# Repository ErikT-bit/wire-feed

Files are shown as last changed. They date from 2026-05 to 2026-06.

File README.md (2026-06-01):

# Wire EDM Wire-Feed System

This repository contains the software, supporting libraries, and mechanical CAD files for a Wire EDM wire-feed and wire-tension system.

The system uses a motor-driven wire-pull mechanism and an electronically controlled wire brake. The brake is implemented with a moteus motor controller and is intended to maintain controlled resistance on the wire spool while the wire is pulled through the machine.

## Repository Layout

```text
wire-feed/
|-- code/
|   |-- pi_brake_controller/
|   `-- WireTension code V1/
|-- libraries/
`-- mechanical/
```

## `code/`

This directory contains the project-specific control software.

### `code/pi_brake_controller/`

This is the current Raspberry Pi brake-controller implementation.

The software supports communication between the machine controller and the moteus-based wire brake. The folder includes the Raspberry Pi brake daemon, operator-facing console, service configuration, autostart configuration, hardware-detection utility, and a fake brake server for testing without hardware.

The Raspberry Pi brake-controller code in this folder was written by Nathan Taylor with development assistance from Claude Code.

See [`code/pi_brake_controller/README.md`](code/pi_brake_controller/README.md) for the system architecture, setup instructions, operator workflow, troubleshooting notes, and file-by-file authorship credit.

### `code/WireTension code V1/`

This folder contains an earlier version of the wire-tension control software. It is retained as a reference for the development history of the project.

## `libraries/`

This directory contains supporting libraries retained with the project for development and reference.

Included libraries:

- `ACAN2517`
- `ACAN2517FD`
- `AccelStepper`
- `HX711_Arduino_Library`
- `Moteus`

These libraries are third-party dependencies or reference libraries. Their original licenses, README files, and attribution information are preserved inside their respective folders.

## `mechanical/`

This directory contains the mechanical CAD files for the Wire EDM wire-feed and wire-tension hardware.

The folder includes:

- Native SolidWorks assembly files
- Native SolidWorks part files
- Exported `.STEP`, `.STL`, and `.3mf` files
- Files organized by subsystem, including pulleys, nozzles, custom tools, the wire-collection system, the wire-pull axle assembly, and the wire-tension housing

See [`mechanical/README.md`](mechanical/README.md) for the detailed CAD-file inventory and mechanical-design credit.

## Calibration And Tuning Data

Calibration data and the tuning workflow used during development are kept in a separate repository:

[Wire-EDM-Tension-Calibration](https://github.com/ErikT-bit/Wire-EDM-Tension-Calibration)

The `data/` folder is not part of this repository layout for the GitHub push.

## Important Note About Moteus Brake Tuning

The moteus controller must be tuned for the specific motor and mechanical setup being used.

The `Kd` values used in this project were developed for this particular wire-brake assembly, motor, spool geometry, pulley arrangement, and operating range. Those values should **not** be assumed to work correctly or safely in another system.

Anyone adapting this project should calibrate and test their own wire brake before operating the machine. A different motor, spool diameter, gear ratio, pulley layout, wire path, or target tension range may require different moteus settings and different `Kd` values.

## Project Documentation

Additional documentation is available inside the relevant folders:

- [`code/pi_brake_controller/README.md`](code/pi_brake_controller/README.md) - brake-controller architecture, setup, operation, troubleshooting, and software credit
- [`mechanical/README.md`](mechanical/README.md) - CAD-file inventory and mechanical-design credit

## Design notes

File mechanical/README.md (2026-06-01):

# Mechanical CAD Files

This directory contains the mechanical CAD models, assemblies, and exported manufacturing files for the Wire EDM wire-feed and wire-tension system.

Some designs appear in more than one file format or in more than one subsystem folder. Native SolidWorks files are included where available, while `.STEP`, `.STL`, and `.3mf` files are included for manufacturing, sharing, or 3D printing.

## Folder Layout

- `CAD Assembly Files/` - native SolidWorks assemblies
- `CAD PART Files/` - native SolidWorks parts and some assembly files stored with their related parts
- `CAD STEP Files/` - exported manufacturing and sharing files, organized by subsystem
- `CAD STEP Files/Custom Tools/` - tool and calibration exports
- `CAD STEP Files/Nozzles/` - nozzle exports
- `CAD STEP Files/Pulleys/` - pulley exports
- `CAD STEP Files/Wire Collection System/` - wire collection subsystem exports
- `CAD STEP Files/Wire Pull Axle Assembly/` - wire-pull axle subsystem exports
- `CAD STEP Files/Wire Tension Housing/` - wire-tension housing subsystem exports

SolidWorks lock or owner files beginning with `~$` are not design-credit entries.

## Contributors

### Nathan Erik Taylor

The following specific CAD designs and exported files were created by **Nathan Erik Taylor**.

#### SolidWorks Assembly Files

Located in `CAD Assembly Files/`.

- `EDM Spool Small.SLDASM`
- `EDM Wire Tension Housing Assembly V6.SLDASM`

#### SolidWorks Part And Assembly Files

Located in `CAD PART Files/`.

- `Captured Pulley V5.SLDPRT`
- `EDM Axle Support.SLDPRT`
- `EDM Bambu Inner Spool With Bearings.SLDPRT`
- `EDM Brake_Motor_Mount_Plate.SLDPRT`
- `EDM Custom Spool 1 of 2.SLDPRT`
- `EDM Custom Spool 2 of 2.SLDPRT`
- `EDM Custom Spool Small.SLDASM`
- `EDM Driver Pulley V4.SLDPRT`
- `EDM Power Cover.SLDPRT`
- `EDM Pulley-Spacer.SLDPRT`
- `EDM Receiver Nozzle.SLDPRT`
- `EDM Receiver Pulley.SLDPRT`
- `EDM Shrinkage Gauge.SLDPRT`
- `EDM Sled Spacer V2.SLDPRT`
- `EDM Slip Spool (split for assembly).SLDPRT`
- `EDM Spool Ends.SLDPRT`
- `EDM Threading Tool.SLDPRT`
- `EDM V2-Spool Mount (LEFT and RIGHT).SLDPRT`
- `EDM Water nozzel V8 (with 10mm hole).SLDPRT`
- `EDM Wire Bumper.SLDPRT`
- `EDM Wire Home Calibration Part 1 of 2.SLDPRT`
- `EDM Wire Home Calibration Part 2 of 2.SLDPRT`
- `EDM Wire Tension Housing Assembly V6.SLDASM`
- `Threaded pulley reverse thread V5.SLDPRT`

#### Exported CAD Files

##### Custom Tools

Located in `CAD STEP Files/Custom Tools/`.

- `EDM Shrinkage Gauge.STEP`
- `EDM Threading Tool.STEP`
- `EDM Wire Home Calibration Part 1 of 2.STEP`
- `EDM Wire Home Calibration Part 2 of 2.STEP`

##### Nozzles

Located in `CAD STEP Files/Nozzles/`.

- `EDM Receiver Nozzle.STEP`
- `EDM Water nozzel V8 (with 10mm hole).STEP`

##### Pulleys

Located in `CAD STEP Files/Pulleys/`.

- `Captured Pulley V5.STEP`
- `EDM Driver Pulley V4.STEP`
- `EDM Pulley-Spacer.3mf`
- `EDM Receiver Pulley.STEP`
- `Threaded pulley reverse thread V5.STEP`

##### Wire Collection System

Located in `CAD STEP Files/Wire Collection System/`.

- `EDM Bambu Inner Spool With Bearings.STEP`
- `EDM Custom Spool 1 of 2.STEP`
- `EDM Custom Spool 2 of 2.STEP`
- `EDM Slip Spool (split for assembly).STEP`
- `EDM Spool Ends.STEP`
- `EDM V2-Spool Mount (LEFT and RIGHT).STEP`

##### Wire Pull Axle Assembly

Located in `CAD STEP Files/Wire Pull Axle Assembly/`.

- `EDM Axle Support.STEP`
- `EDM Driver Pulley V4.STEP`
- `EDM Pulley-Spacer.STEP`
- `EDM Sled Spacer V2.STEP`

##### Wire Tension Housing

Located in `CAD STEP Files/Wire Tension Housing/`.

- `Captured Pulley V5.STEP`
- `EDM Brake_Motor_Mount_Plate.STEP`
- `EDM FACEPLATE.3mf`
- `EDM FACEPLATE.STEP`
- `EDM Power Cover.STEP`
- `EDM Wire Bumper.STEP`
- `EDM Wire Tension Housing Assembly V6.STEP`
- `Threaded pulley reverse thread V5.STEP`

### @koolm

The following pulley files were generated using a MakerWorld generative design tool created by **@koolm**.

#### Pulleys

Located in `CAD STEP Files/Pulleys/`.

- `18 Tooth T5 Pulley 8mm bore.3mf`
- `EDM 59 Tooth 8mm bore.stl`

#### Copies Used In Subsystem Folders

- `CAD STEP Files/Wire Collection System/18 Tooth T5 Pulley 8mm bore.3mf`
- `CAD STEP Files/Wire Pull Axle Assembly/EDM 59 Tooth 8mm bore.stl`

### Jacob Kasch

Files contributed by **Jacob Kasch** can be listed here as they are added.

### Kieran Dolan

Files contributed by **Kieran Dolan** can be listed here as they are added.

### Jorge Sandoval

Files contributed by **Jorge Sandoval** can be listed here as they are added.

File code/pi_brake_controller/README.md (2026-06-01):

# Wire EDM Brake Controller

Electronic braking system for a Wire EDM machine. The brake torque is
delivered by a moteus r4.11 motor controller acting as a velocity-zero
damper on the wire spool. A Raspberry Pi 3B+ commands the moteus over
CAN-FD via a pi3hat r4.5; a Raspberry Pi 5 (LinuxCNC main controller)
provides the operator interface over an ethernet TCP link.

The operator never has to log into the Pi 3 or know any "machine codes" —
they sit in front of the Pi 5, see plain-English prompts on screen, and
type a velocity and tension. The Pi 3 computes the moteus damping value
and engages the brake.

## System architecture

```
                +-----------------------------+
                |  Raspberry Pi 5 (LinuxCNC)  |
                |  10.10.10.1                 |
                |  - Mesa motion via hm2_eth  |
                |  - brake_console.py (xterm) |
                +--------------+--------------+
                               |
                               | ethernet
                               v
                +--------------+--------------+
                |    Unmanaged ethernet switch    |
                +--+-------------+-------------+--+
                   |             |             |
                   |             |             |
        +----------+--+   +------+------+   +--+----------+
        | Mesa 7i76EU |   | Raspberry  |   |             |
        | 10.10.10.10 |   | Pi 3B+     |   | (laptop, when
        | (motion)    |   | 10.10.10.20|   |  pushing code)
        +-------------+   +-----+------+   +-------------+
                                |
                                | pi3hat r4.5 -> CAN bus 1 (JC1)
                                v
                        +-------+-------+
                        | moteus r4.11  |
                        | (electric     |
                        |  brake)       |
                        +---------------+
                                |
                                | 3-phase
                                v
                        +-------+-------+
                        | BLDC on wire  |
                        | spool         |
                        +---------------+
```

## Hardware

| Item | Role | Notes |
|---|---|---|
| Raspberry Pi 5 | Machine main / operator UI | Runs LinuxCNC + Mesa driver + brake console |
| Raspberry Pi 3B+ | Brake controller | Headless, runs `wire_brake.py` as a systemd service |
| pi3hat r4.5 | CAN-FD interface | Sits on the Pi 3B+'s 40-pin GPIO header |
| moteus r4.11 | Motor controller / brake | Connected to pi3hat JC1 (CAN bus 1), CAN ID 1 |
| 24 V bench supply | moteus high-voltage power | ~12–44 V is acceptable |
| Mesa 7i76EU | Motion controller for the wire-puller | Static IP 10.10.10.10 (factory default) |
| Unmanaged ethernet switch | Connects Pi 5, Pi 3B+, Mesa | No DHCP, all devices use static IPs |

## Network configuration

| Device | IP / subnet | Notes |
|---|---|---|
| Pi 5 (`eth0`) | `10.10.10.1/24`  | NetworkManager static profile |
| Mesa 7i76EU | `10.10.10.10/24` | Factory default, do not change |
| Pi 3B+ (`eth0`) | `10.10.10.20/24` | NetworkManager static profile |

The Pi 5 also has WiFi (`wlan0`) for development/file-transfer; it is not
used by the brake system. The Pi 3B+ is intended to be wired-only at the
machine.

## Files

| File | Where it runs | Purpose |
|---|---|---|
| `wire_brake.py` | Pi 3B+ | TCP server daemon; talks to moteus, runs the brake state machine |
| `brake_console.py` | Pi 5 | Operator-facing TCP client; relays text to/from `wire_brake.py` |
| `detect_moteus.py` | Pi 3B+ | One-shot moteus communication test, no motion |
| `fake_brake_server.py` | Anywhere | Stand-in for `wire_brake.py` for testing without hardware |
| `wire-brake.service` | Pi 3B+ (`/etc/systemd/system/`) | systemd unit for auto-start at boot |
| `brake-console.desktop` | Pi 5 (`~/.config/autostart/`) | XFCE autostart entry for the operator console |

## The brake control law

The moteus runs in `position` mode with `position = NaN`, `velocity = 0`,
`kp_scale = 0`, and `kd_scale = Kd`. With `kp_scale = 0` the position term
is disabled, so the controller only resists *motion* — exactly what a
brake should do. The braking torque is proportional to the velocity the
puller forces on the spool.

The damping coefficient `Kd` is computed from the operator's requested
wire speed and tension using a fitted equation:

```
Kd = 0.560 - 0.218 v + 2.246 T - 0.107 v T + 0.0126 v^2 - 0.122 T^2
```

where `v` is wire velocity in m/min and `T` is wire tension in kgf.

The equation is calibrated for the envelope `v ∈ [5, 15] m/min`,
`T ∈ [0.2, 3] kgf`. Inputs outside that envelope are rejected before any
moteus command is issued.

## Pi 3B+ setup

One-time install steps. Assumes Raspberry Pi OS 64-bit (Lite or Desktop)
and a user named `admin` with a home directory at `/home/admin`.

### 1. System packages

```bash
sudo apt update
sudo apt install -y tmux python3-pip python3-venv python3-dev build-essential git
```

### 2. Enable SPI (required by pi3hat)

```bash
sudo raspi-config nonint do_spi 0
```

### 3. Bump swap to 2 GB (recommended on the 1 GB Pi 3B+ for the moteus install)

```bash
sudo dphys-swapfile swapoff
sudo sed -i 's/^CONF_SWAPSIZE=.*/CONF_SWAPSIZE=2048/' /etc/dphys-swapfile
sudo dphys-swapfile setup
sudo dphys-swapfile swapon
```

### 4. Install moteus + moteus-pi3hat in a venv

```bash
mkdir -p ~/moteus && cd ~/moteus
python3 -m venv venv
source venv/bin/activate
pip install --upgrade pip wheel setuptools
pip install moteus moteus-pi3hat
```

### 5. Drop the brake controller files into `~/wirebrake/`

Copy `wire_brake.py`, `detect_moteus.py`, and `wire-brake.service` to
`/home/admin/wirebrake/`. Either via scp from a laptop or by cloning this
repo and copying out of `WireTension/`.

### 6. Install the systemd service

```bash
sudo cp ~/wirebrake/wire-brake.service /etc/systemd/system/wire-brake.service
sudo systemctl daemon-reload
sudo systemctl enable --now wire-brake.service
sudo systemctl status wire-brake
```

You should see `active (running)` and `[boot] listening on ('0.0.0.0', 5005)`
in the journal output.

### 7. Static ethernet IP (run at the Pi 3B+ console)

```bash
sudo nmcli con mod "Wired connection 1" ipv4.method manual ipv4.addresses 10.10.10.20/24 ipv6.method disabled
sudo nmcli con down "Wired connection 1"; sudo nmcli con up "Wired connection 1"
ip a show eth0
```

Confirm `inet 10.10.10.20/24` is shown on `eth0`.

## Pi 5 setup

Assumes the LinuxCNC bundled Debian image with NetworkManager and XFCE
desktop, user `admin`.

### 1. Static ethernet IP

```bash
sudo nmcli con mod "Wired connection 1" ipv4.method manual ipv4.addresses 10.10.10.1/24 ipv6.method disabled
sudo nmcli con down "Wired connection 1"; sudo nmcli con up "Wired connection 1"
```

### 2. Install xterm

```bash
sudo apt install -y xterm
```

### 3. Drop the console files in place

- `brake_console.py` → `/home/admin/wirebrake/brake_console.py`
- `brake-console.desktop` → `/home/admin/.config/autostart/brake-console.desktop`

### 4. Enable desktop auto-login (optional but recommended)

```bash
sudo raspi-config nonint do_boot_behaviour B4
```

`B4` = Desktop Autologin. After this, the Pi 5 boots straight into the
admin desktop session and the brake console window opens automatically.

### 5. Reboot

```bash
sudo reboot
```

When the desktop comes up, an xterm titled "Wire EDM Brake Console" should
auto-open and immediately show the velocity prompt from the Pi 3.

## Operator workflow

1. Power on the cabinet (Pi 5, Pi 3, Mesa, 24 V supply for the moteus).
2. Wait ~30 seconds. The Pi 5 boots into desktop, the brake console window
   opens, and the velocity prompt appears.
3. Operator types the desired wire velocity in m/min, presses Enter.
4. Tension prompt appears. Operator types tension in kgf, presses Enter.
5. Brake engages. The console shows `Brake engaged. Kd = ...`.
6. When done with the cut, operator types `stop`. Brake disengages.
7. `Resume with previous values? (y/n)` — `y` re-engages with the same
   v/T, `n` returns to the velocity prompt for new values.

If the connection drops, the brake daemon makes the motor safe and the
console attempts to reconnect every two seconds. If the moteus reports a
fault while engaged, the brake stops and the console moves to the resume
prompt.

## Development & testing without hardware

You can exercise the full operator UX (every prompt, validation message,
state transition) without a real Pi 3B+ or moteus by running the fake
server. On any machine with Python 3:

```bash
# Terminal A — fake server (acts like wire_brake.py over TCP)
python3 fake_brake_server.py

# Terminal B — operator console
python3 brake_console.py 127.0.0.1 5005
```

The fake server logs `[fake-brake] engage  kd=X.XXXX` instead of actually
commanding a motor. Useful for testing edge cases (out-of-range numbers,
invalid input, mid-engaged disconnect) without risking the hardware.

The real `wire_brake.py` also has a `--sim` mode that converses on
stdin/stdout instead of TCP, useful for one-off debugging at a Pi 3B+
console:

```bash
sudo /home/admin/moteus/venv/bin/python /home/admin/wirebrake/wire_brake.py --sim
```

## Wire protocol

The TCP link between Pi 5 and Pi 3B+ carries plain ASCII text — no machine
codes. The Pi 3B+ owns all UI text; the Pi 5 just relays bytes.

Lines from Pi 3 → Pi 5 are prompts, status, and error messages, e.g.

```
What velocity do you want the wire to be pulled at (m/min)?
Pick a value between 5.0-15.0:
Brake engaged.  Kd = 2.1030  (v=10.0 m/min, T=1.5 kgf)
  3.0 is out of range.  Must be 0.2 to 3.0.
Brake stopped — moteus fault code 32.
```

Lines from Pi 5 → Pi 3 are operator input, e.g.

```
10
1.5
stop
y
?            (refresh: re-display the current prompt)
```

The protocol is intentionally human-readable so a developer can `nc
10.10.10.20 5005` from anywhere on the LAN to drive the brake by hand.

## Troubleshooting

### Pi 3B+ won't boot / boot loop

Most often **under-voltage**. Pi 3B+ with pi3hat needs a steady 5 V at
≥2.5 A. Check that the red PWR LED is solid (not blinking or off) during
boot. Use the official Raspberry Pi 5V supply or equivalent.

If the LEDs are fine but it still loops, try removing the pi3hat — if it
boots without the HAT, the HAT is either drawing too much or not seated
flat on the GPIO header.

### moteus does not respond

Run `python3 detect_moteus.py` from `~/wirebrake/` (with the venv active or
via `sudo /home/admin/moteus/venv/bin/python3 detect_moteus.py`). Errors
narrow down to:

- pi3hat not seated on the GPIO header
- moteus 24 V power off
- CAN_H/CAN_L wiring swapped on JC1
- moteus CAN ID isn't 1 (use `moteus_tool` to check/change)

### "Realtime scheduler" error from moteus_pi3hat

The pi3hat library needs `CAP_SYS_NICE`. Either run with `sudo`, or
permanently grant the capability to your venv's Python:

```bash
sudo setcap cap_sys_nice+ep /home/admin/moteus/venv/bin/python3
```

The systemd service runs as root and avoids this.

### Pi 5 console window doesn't auto-open

- Confirm desktop auto-login is enabled (Section "Pi 5 setup" step 4).
- Confirm `~/.config/autostart/brake-console.desktop` exists and the path
  in its `Exec=` line points at your real `brake_console.py`.
- Check the XFCE session log: `~/.xsession-errors`.

### `brake_console.py` says "Waiting for brake controller..."

That means the Pi 5 reaches the network but the Pi 3 isn't responding on
`10.10.10.20:5005`. Either the Pi 3 isn't powered, the static IP didn't
take, or the `wire-brake.service` is down. From the Pi 5:

```bash
ping -c 3 10.10.10.20
ssh admin@10.10.10.20 sudo systemctl status wire-brake
```

## Future work

- **Closed-loop tension control.** Today the brake runs open-loop on the
  operator-entered `v`. The original spec calls for the brake to retune
  Kd in real time based on the puller motor's encoder velocity. The
  protocol already supports live `PARAMS,v,T` updates while engaged —
  the Pi 5 needs to emit them based on Mesa encoder data.

- **Graceful shutdown button.** A "Power Down" button in the operator
  UI that disengages the brake, SSHs `sudo poweroff` to the Pi 3, then
  shuts down the Pi 5. Avoids SD-card corruption from yanking power.

- **LinuxCNC integration.** Replace the standalone xterm console with a
  HAL component or a glade panel inside the LinuxCNC UI, so the brake
  parameters live in the same screen as the rest of the machine controls.

## License

TBD — pick one and add a LICENSE file if you intend to publish.

## Authorship and development credit

The Raspberry Pi brake-controller software and supporting configuration files in this directory were created by **Nathan Taylor** with development assistance from **Claude Code**.

Files authored and assembled for this brake-controller system:

- `brake_console.py`
- `detect_moteus.py`
- `fake_brake_server.py`
- `wire_brake.py`
- `brake-console.desktop`
- `wire-brake.service`

This `README.md` documentation was also prepared for the brake-controller system by **Nathan Taylor** with assistance from **Claude Code**.

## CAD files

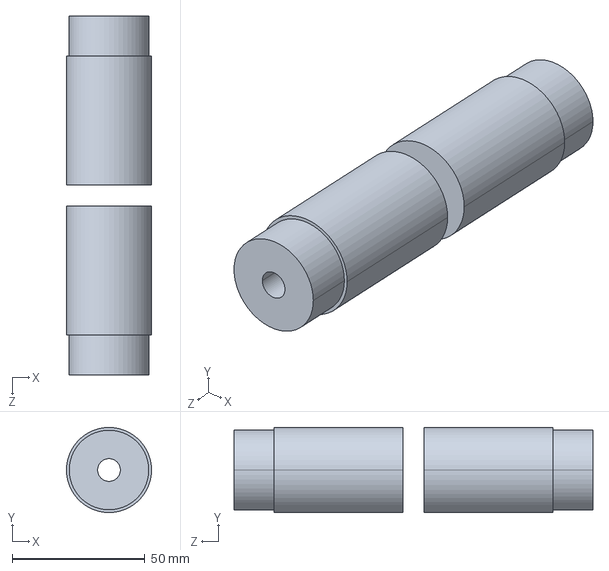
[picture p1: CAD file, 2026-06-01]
mechanical/CAD STEP Files/Wire Collection System/EDM Slip Spool (split for assembly).STEP
32.0 x 32.0 x 135.0 mm

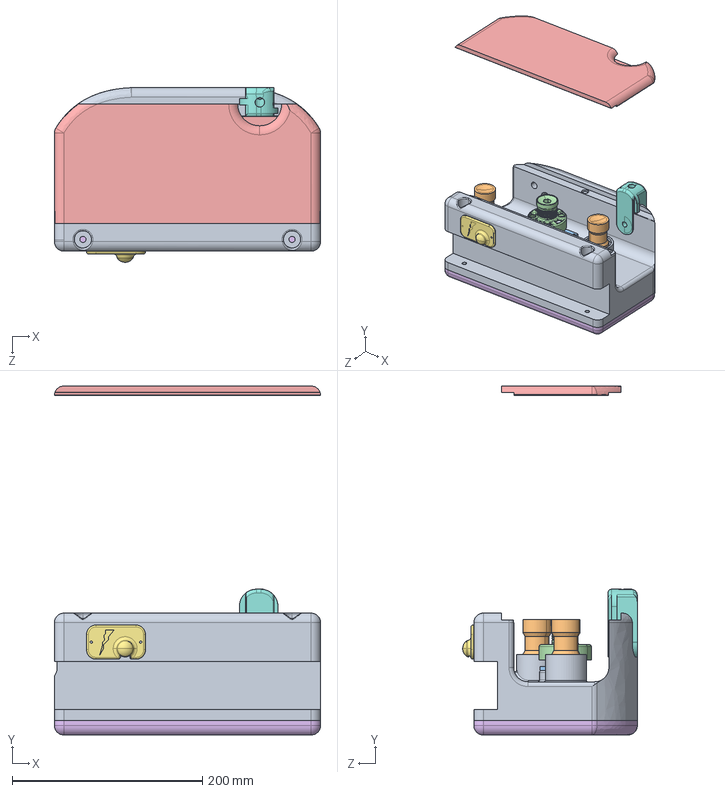
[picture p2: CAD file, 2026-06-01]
mechanical/CAD STEP Files/Wire Tension Housing/EDM Wire Tension Housing Assembly V6.STEP
280.0 x 367.1 x 183.8 mm
EDM V3 Mainbody
Captured Pulley V5 x 2
Motor_Mount_Plate
Threaded pulley reverse thread V5
EDM V3 Faceplate V2
EDM V3 Backplate
EDM Power Cover
nozzel V7 (with 10mm hole)

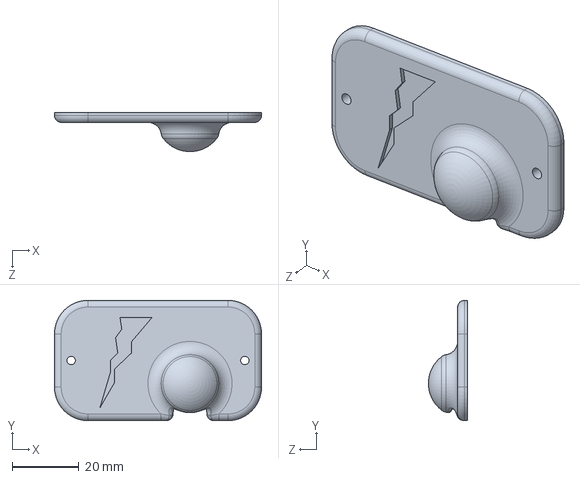
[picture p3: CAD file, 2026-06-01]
mechanical/CAD PART Files/EDM Power Cover.SLDPRT
62.0 x 36.0 x 11.8 mm

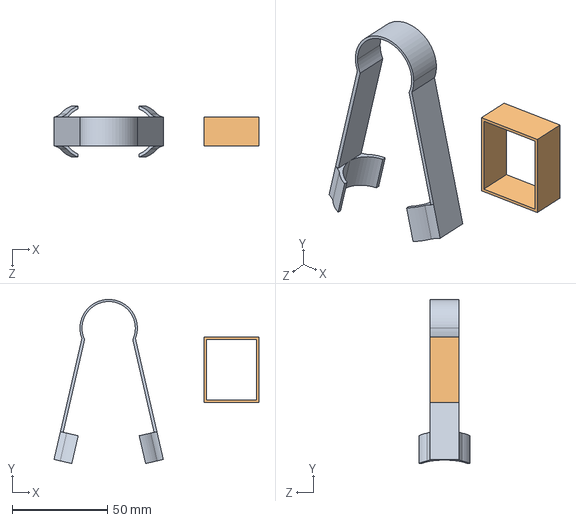
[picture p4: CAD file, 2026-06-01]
mechanical/CAD STEP Files/Custom Tools/EDM Threading Tool.STEP
107.7 x 86.3 x 26.9 mm

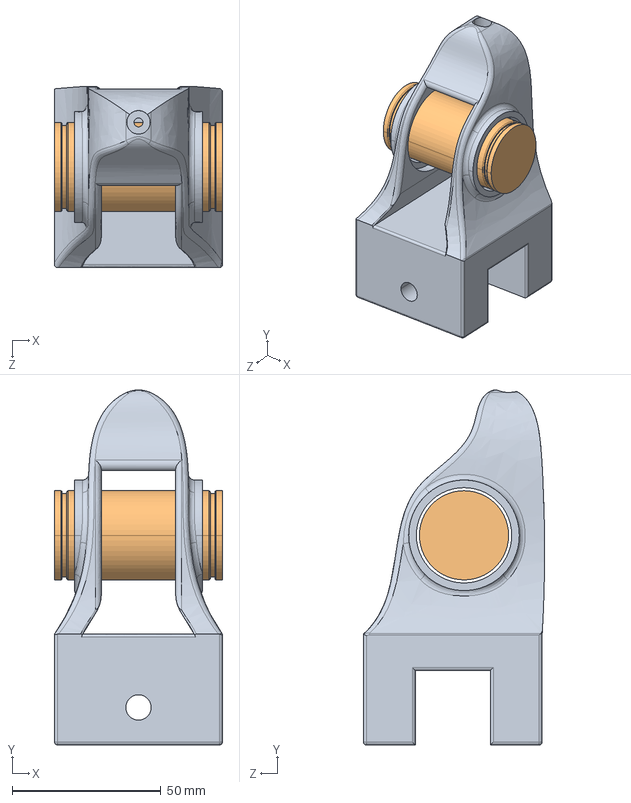
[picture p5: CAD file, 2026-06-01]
mechanical/CAD STEP Files/Nozzles/EDM Receiver Nozzle.STEP
56.4 x 119.2 x 60.8 mm

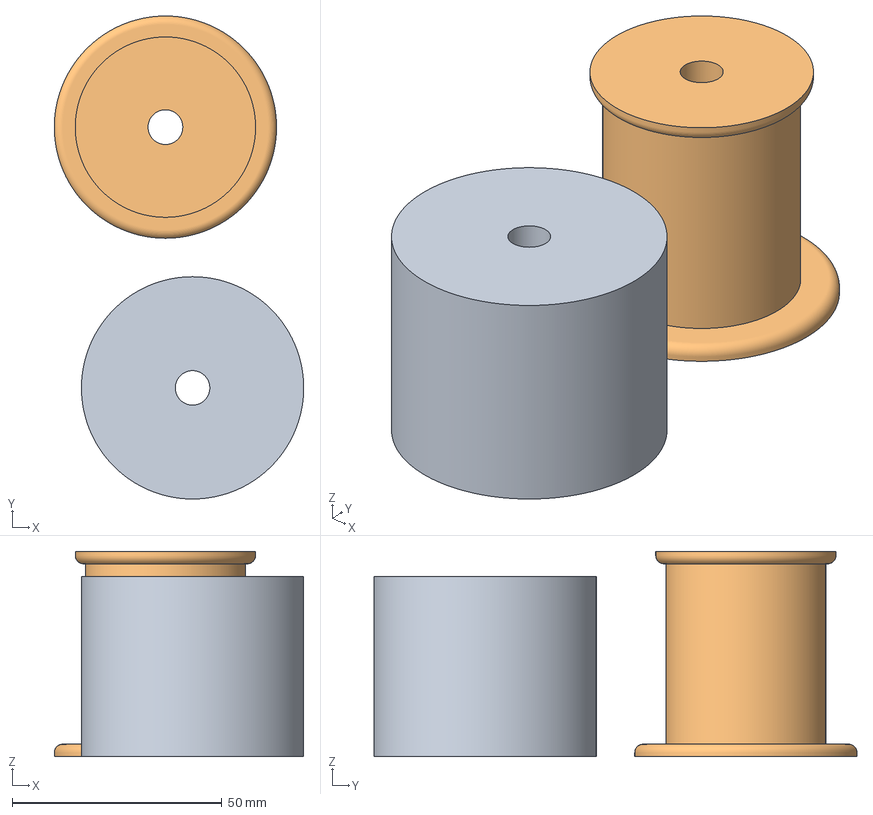
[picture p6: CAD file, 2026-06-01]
mechanical/CAD STEP Files/Pulleys/EDM Pulley-Spacer.3mf
59.5 x 115.2 x 49.0 mm
EDM Pulley-Spacer.STEP
EDM Driver Pulley V3 or V4.STEP

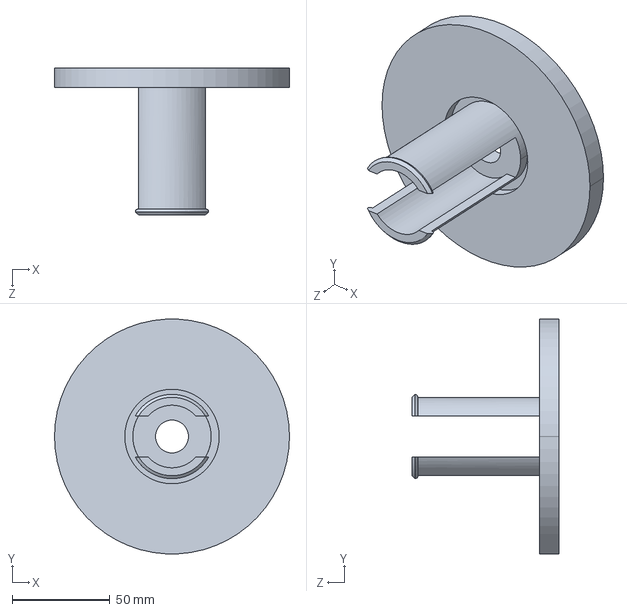
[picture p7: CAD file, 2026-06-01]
mechanical/CAD STEP Files/Wire Collection System/EDM Custom Spool 2 of 2.STEP
120.0 x 119.8 x 75.0 mm

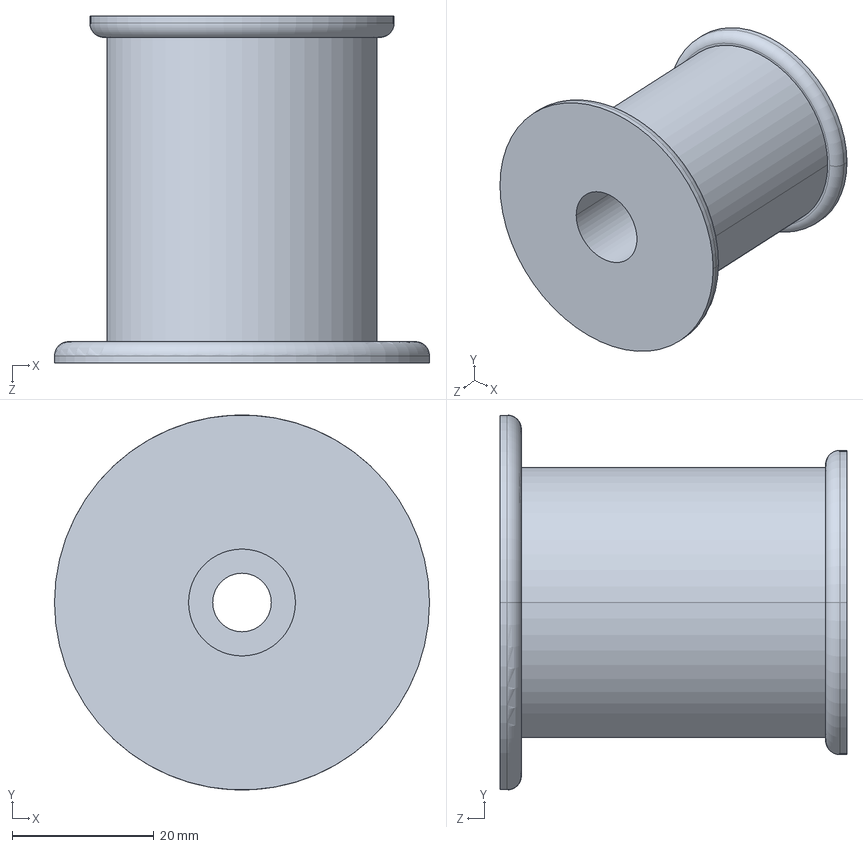
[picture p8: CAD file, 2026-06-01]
mechanical/CAD STEP Files/Wire Pull Axle Assembly/EDM Driver Pulley V4.STEP
53.0 x 53.0 x 49.0 mm

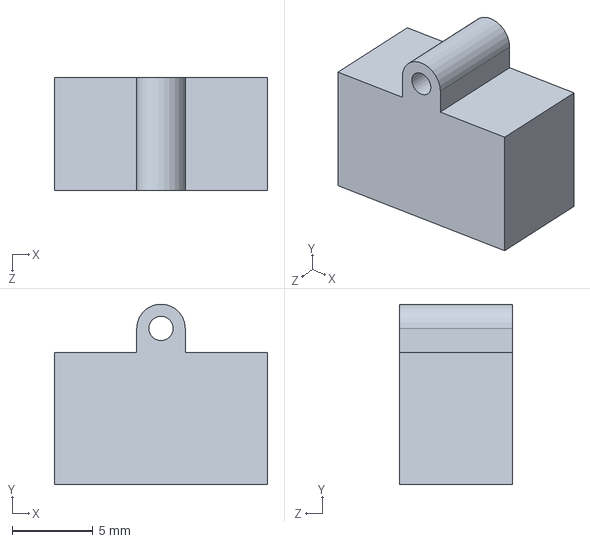
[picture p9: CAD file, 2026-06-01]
mechanical/CAD PART Files/EDM Wire Home Calibration Part 2 of 2.SLDPRT
13.1 x 11.1 x 7.00 mm

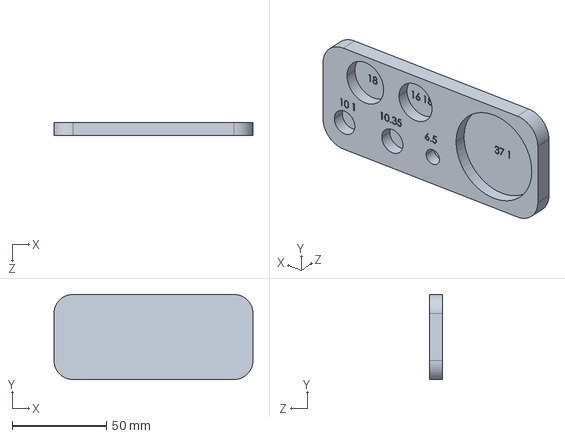
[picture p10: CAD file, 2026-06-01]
mechanical/CAD STEP Files/Custom Tools/EDM Shrinkage Gauge.STEP
105.3 x 45.0 x 7.00 mm

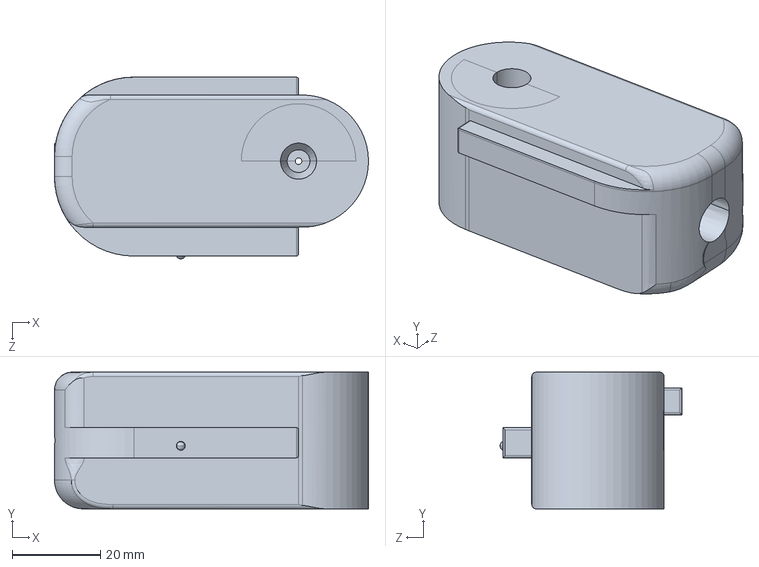
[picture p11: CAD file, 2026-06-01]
mechanical/CAD STEP Files/Nozzles/EDM Water nozzel V8 (with 10mm hole).STEP
71.2 x 31.0 x 41.2 mm

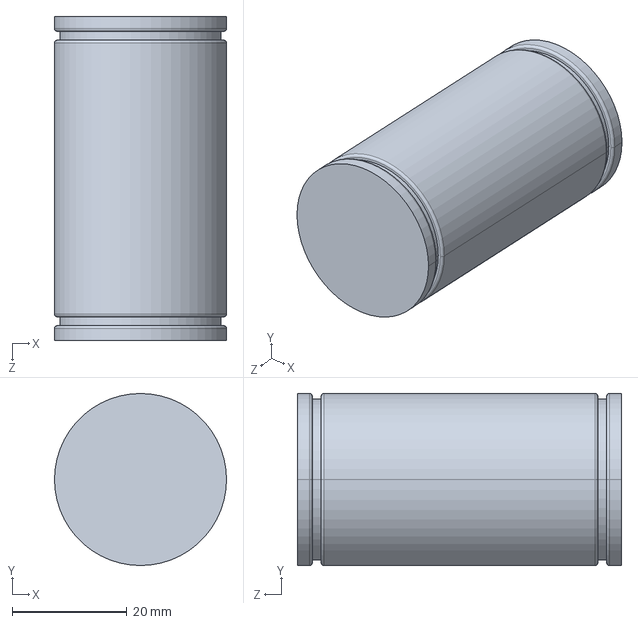
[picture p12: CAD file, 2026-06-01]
mechanical/CAD STEP Files/Pulleys/EDM Receiver Pulley.STEP
30.0 x 30.0 x 56.4 mm

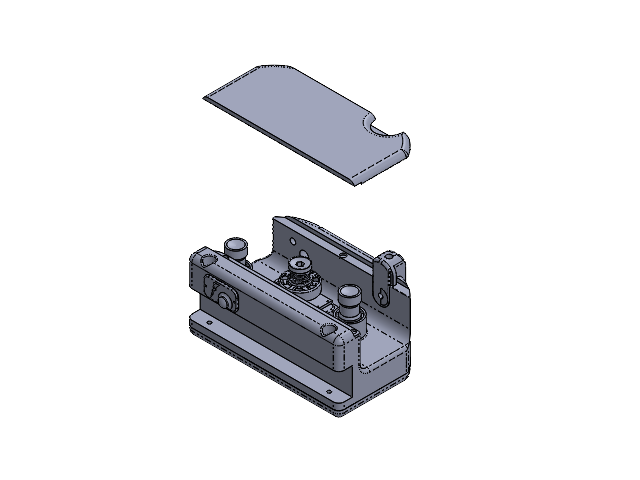
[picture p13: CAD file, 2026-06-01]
mechanical/CAD Assembly Files/EDM Wire Tension Housing Assembly V6.SLDASM
EDM V3 Mainbody
Captured Pulley V5 x 2
Motor_Mount_Plate
Threaded pulley reverse thread V5
EDM V3 Faceplate V2
EDM V3 Backplate
EDM Power Cover
nozzel V7 (with 10mm hole)

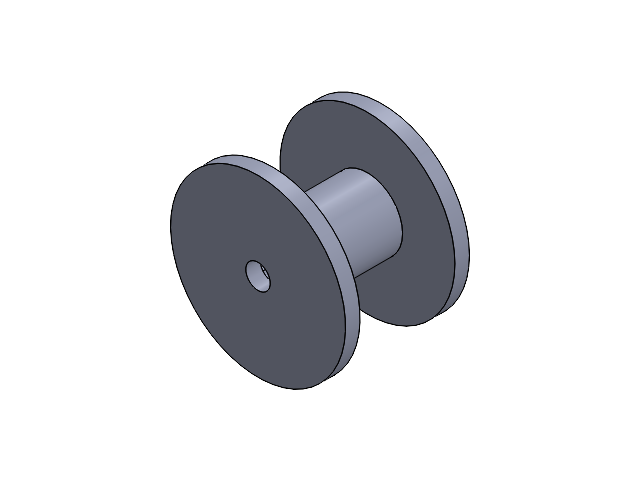
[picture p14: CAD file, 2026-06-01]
mechanical/CAD Assembly Files/EDM Spool Small.SLDASM
EDM Spool
EDM Spool B-half

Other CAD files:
mechanical/CAD PART Files/EDM Custom Spool Small.SLDASM
mechanical/CAD PART Files/EDM Slip Spool (split for assembly).SLDPRT
mechanical/CAD PART Files/EDM Wire Tension Housing Assembly V6.SLDASM
mechanical/CAD STEP Files/Wire Tension Housing/EDM Power Cover.STEP
mechanical/CAD PART Files/Captured Pulley V5.SLDPRT
mechanical/CAD PART Files/EDM Axle Support.SLDPRT
mechanical/CAD PART Files/EDM Bambu Inner Spool With Bearings.SLDPRT
mechanical/CAD PART Files/EDM Brake_Motor_Mount_Plate.SLDPRT
mechanical/CAD PART Files/EDM Custom Spool 1 of 2.SLDPRT
mechanical/CAD PART Files/EDM Custom Spool 2 of 2.SLDPRT
mechanical/CAD PART Files/EDM Driver Pulley V4.SLDPRT
mechanical/CAD PART Files/EDM Pulley-Spacer.SLDPRT
mechanical/CAD PART Files/EDM Receiver Nozzle.SLDPRT
mechanical/CAD PART Files/EDM Receiver Pulley.SLDPRT
mechanical/CAD PART Files/EDM Shrinkage Gauge.SLDPRT
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

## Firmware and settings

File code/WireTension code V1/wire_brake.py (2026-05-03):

#!/usr/bin/env python3
"""
wire_brake.py — Wire EDM brake controller for the Pi 3B+ + pi3hat r4.5.

System architecture
-------------------
    Pi 5 (LinuxCNC, runs brake_console.py for the operator)
        |
        | TCP/IP over ethernet (port 5005, conversation in plain text)
        |
    Pi 3B+ (this script — runs as a systemd service)
        |
        | pi3hat r4.5 -> CAN bus 1 (JC1 port)
        |
    moteus r4.11 (electric brake)

The wire is pulled by a separate motor, driven by the Mesa motion
controller on the Pi 5 / LinuxCNC side.  The moteus on this Pi acts
purely as a damping brake: velocity = 0 with kd_scale = computed Kd, so
the moteus produces a braking torque proportional to motion.

Conversation model
------------------
This script owns the UI text.  It sends prompts and status messages over
the TCP socket; the operator (via brake_console.py on the Pi 5) sees
those prompts and types replies.  No machine codes.  The state machine
walks the operator through:

    1. ASK_V     "What velocity do you want the wire to be pulled at..."
    2. ASK_T     "What tension do you want the wire to be held at..."
    3. ENGAGED   brake is held with computed Kd; type 'stop' to release.
    4. ASK_RESUME on stop or fault: "Resume with previous values? (y/n)"
       -> y : back into ENGAGED with the same Kd
       -> n : back to ASK_V (start over)

Out-of-range or unparseable answers are rejected with a friendly note
and the same prompt is re-issued.  Single line of input '?' anywhere
re-displays the current prompt (the brake_console sends '?' on connect
so the operator's screen always shows the live prompt, no matter when
the Pi 5 boots relative to the Pi 3).

If the TCP client disconnects mid-session, the brake is safed and the
service waits for the next client.  Designed to run as a systemd service,
never exits voluntarily.

Usage
-----
    # Production: TCP server on all interfaces, port 5005 (default)
    sudo /home/admin/moteus/venv/bin/python wire_brake.py

    # Custom port
    sudo /home/admin/moteus/venv/bin/python wire_brake.py --port 5010

    # Bench test with no Pi 5 — converse on stdin/stdout
    sudo /home/admin/moteus/venv/bin/python wire_brake.py --sim
"""

import argparse
import asyncio
import math
import sys

import moteus
import moteus_pi3hat


# ---------- Hardware constants ------------------------------------------------
MOTEUS_ID        = 1
MOTEUS_BUS       = 1      # JC1 on the pi3hat
MAX_TORQUE_NM    = 5.0
CONTROL_PERIOD_S = 0.05   # re-issue brake cmd every 50 ms (watchdog ~100 ms)
FAULT_POLL_EVERY = 20     # query moteus state every N control cycles (~1 s)

# ---------- TCP defaults ------------------------------------------------------
DEFAULT_HOST = "0.0.0.0"   # listen on all interfaces
DEFAULT_PORT = 5005

# ---------- Calibrated input ranges -------------------------------------------
V_MIN, V_MAX = 5.0, 15.0   # wire velocity, m/min
T_MIN, T_MAX = 0.2, 3.0    # wire tension,  kgf

# ---------- Daemon retry on hard error ----------------------------------------
RETRY_DELAY_S = 2.0


# ---------- Kd equation -------------------------------------------------------
def calculate_kd(v_m_per_min: float, T_kgf: float) -> float:
    """Kd = 0.560 - 0.218 v + 2.246 T - 0.107 v T + 0.0126 v^2 - 0.122 T^2"""
    if not (V_MIN <= v_m_per_min <= V_MAX):
        raise ValueError(
            f"velocity {v_m_per_min} m/min is outside [{V_MIN}..{V_MAX}]."
        )
    if not (T_MIN <= T_kgf <= T_MAX):
        raise ValueError(
            f"tension {T_kgf} kgf is outside [{T_MIN}..{T_MAX}]."
        )
    kd = (
        0.560
        - 0.218 * v_m_per_min
        + 2.246 * T_kgf
        - 0.107 * v_m_per_min * T_kgf
        + 0.0126 * v_m_per_min ** 2
        - 0.122 * T_kgf ** 2
    )
    if kd <= 0:
        raise ValueError(
            f"Kd={kd:.3f} for v={v_m_per_min},T={T_kgf} is non-positive (unstable)."
        )
    return kd


# ---------- Channel abstraction (TCP vs stdin/stdout) -------------------------
class Channel:
    """Send/receive lines of plain text.  send() is synchronous; get_line()
    is async and yields the next received line, blocking until one arrives.
    On a broken connection get_line() raises ConnectionResetError."""

    def send(self, msg: str) -> None:
        raise NotImplementedError

    async def get_line(self) -> str:
        raise NotImplementedError

    def close(self) -> None:
        pass


class TCPChannel(Channel):
    """Wraps an asyncio TCP connection (one client) with line buffering."""

    def __init__(self, reader: asyncio.StreamReader, writer: asyncio.StreamWriter):
        self.reader = reader
        self.writer = writer

    def send(self, msg: str):
        try:
            self.writer.write((msg + "\r\n").encode("utf-8", errors="replace"))
        except Exception:
            pass

    async def get_line(self) -> str:
        try:
            data = await self.reader.readuntil(b"\n")
        except asyncio.IncompleteReadError as e:
            # peer closed the connection
            raise ConnectionResetError("client disconnected") from e
        except (asyncio.LimitOverrunError, ConnectionResetError):
            raise
        return data.decode("utf-8", errors="replace").rstrip("\r\n")

    def close(self):
        try:
            self.writer.close()
        except Exception:
            pass


class StdinChannel(Channel):
    """Stdin/stdout substitute for bench testing without the Pi 5."""

    def __init__(self):
        self._loop = asyncio.get_event_loop()

    def send(self, msg: str):
        print(msg, flush=True)

    async def get_line(self) -> str:
        line = await self._loop.run_in_executor(None, sys.stdin.readline)
        if line == "":
            raise ConnectionResetError("stdin closed")
        return line.rstrip("\r\n")


# ---------- Brake control wrapper around moteus + pi3hat ----------------------
class Brake:
    def __init__(self):
        self.transport = moteus_pi3hat.Pi3HatRouter(
            servo_bus_map={MOTEUS_BUS: [MOTEUS_ID]}
        )
        self.controller = moteus.Controller(id=MOTEUS_ID, transport=self.transport)

    async def initialize(self):
        await self.controller.set_stop()
        await asyncio.wait_for(self.controller.query(), timeout=1.0)

    async def engage(self, kd: float):
        await self.controller.set_position(
            position=math.nan,
            velocity=0.0,
            kp_scale=0.0,
            kd_scale=float(kd),
            maximum_torque=MAX_TORQUE_NM,
            query=False,
        )

    async def query(self):
        return await self.controller.query()

    async def stop(self):
        try:
            await self.controller.set_stop()
        except Exception:
            pass


# ---------- Conversation helpers ----------------------------------------------
def _greet(channel: Channel):
    channel.send("")
    channel.send("==============================================")
    channel.send("  Wire EDM Brake Controller")
    channel.send("==============================================")
    channel.send("")


VELOCITY_PROMPT = (
    "What velocity do you want the wire to be pulled at (m/min)?\r\n"
    f"Pick a value between {V_MIN}-{V_MAX}: "
)
TENSION_PROMPT = (
    "What tension do you want the wire to be held at (kgf)?\r\n"
    f"Pick a value between {T_MIN}-{T_MAX}: "
)


async def _prompt_for_value(channel: Channel, prompt: str,
                            vmin: float, vmax: float) -> float:
    """Ask the operator for a number in [vmin, vmax].  Re-prompts on bad input
    or out-of-range values.  '?' or empty input re-displays the prompt."""
    while True:
        channel.send(prompt)
        line = (await channel.get_line()).strip()
        if line in ("", "?"):
            continue
        try:
            x = float(line)
        except ValueError:
            channel.send(f"  '{line}' is not a number.  Please try again.")
            continue
        if not (vmin <= x <= vmax):
            channel.send(f"  {x} is out of range.  Must be {vmin} to {vmax}.")
            continue
        return x


async def _prompt_yes_no(channel: Channel, prompt: str) -> bool:
    while True:
        channel.send(prompt)
        line = (await channel.get_line()).strip().lower()
        if line in ("y", "yes"):
            return True
        if line in ("n", "no"):
            return False
        channel.send("  Please type 'y' or 'n'.")


async def _hold_until_stop_or_fault(channel: Channel, brake: Brake, kd: float):
    """Re-issues the brake command on a 50 ms cadence, polls the moteus for
    faults every ~1 s, and watches the channel for 'stop'.  Returns:
        ("stop",  None)
        ("fault", "<description>")
        ("error", "<description>")
        ("disconnect", None)         -- TCP client went away mid-engaged
    """
    stop_event = asyncio.Event()
    result = ["stop", None]

    async def hold_task():
        i = 0
        while not stop_event.is_set():
            try:
                await brake.engage(kd)
            except Exception as e:
                result[0] = "error"
                result[1] = repr(e)
                stop_event.set()
                return
            i += 1
            if i % FAULT_POLL_EVERY == 0:
                try:
                    s = await brake.query()
                    fault = int(s.values[moteus.Register.FAULT])
                    if fault != 0:
                        result[0] = "fault"
                        result[1] = f"moteus fault code {fault}"
                        stop_event.set()
                        return
                except Exception as e:
                    result[0] = "error"
                    result[1] = repr(e)
                    stop_event.set()
                    return
            await asyncio.sleep(CONTROL_PERIOD_S)

    async def input_task():
        while not stop_event.is_set():
            try:
                line = (await channel.get_line()).strip().lower()
            except ConnectionResetError:
                result[0] = "disconnect"
                result[1] = None
                stop_event.set()
                return
            if line == "stop":
                result[0] = "stop"
                result[1] = None
                stop_event.set()
                return
            if line in ("?", ""):
                channel.send("  Brake is engaged.  Type 'stop' to disengage.")
            else:
                channel.send(f"  '{line}' ignored — type 'stop' to disengage.")

    h = asyncio.create_task(hold_task())
    i = asyncio.create_task(input_task())
    try:
        await stop_event.wait()
    finally:
        h.cancel()
        i.cancel()
        for t in (h, i):
            try:
                await t
            except asyncio.CancelledError:
                pass
            except Exception:
                pass
    return tuple(result)


# ---------- Main conversation loop --------------------------------------------
async def session(channel: Channel, brake: Brake):
    _greet(channel)
    last_v = last_T = last_kd = None

    while True:  # outer: starts over after a 'no' at resume prompt
        v = await _prompt_for_value(channel, VELOCITY_PROMPT, V_MIN, V_MAX)
        T = await _prompt_for_value(channel, TENSION_PROMPT, T_MIN, T_MAX)
        try:
            kd = calculate_kd(v, T)
        except ValueError as e:
            channel.send(f"  Cannot compute Kd: {e}")
            continue
        last_v, last_T, last_kd = v, T, kd

        while True:  # ENGAGED + ASK_RESUME
            try:
                await brake.engage(kd)
            except Exception as e:
                channel.send(f"  Failed to engage brake: {e!r}")
                break

            channel.send("")
            channel.send(f"Brake engaged.  Kd = {kd:.4f}  (v={v} m/min, T={T} kgf)")
            channel.send("Type 'stop' to disengage when finished.")
            channel.send("")

            outcome, info = await _hold_until_stop_or_fault(channel, brake, kd)
            await brake.stop()

            if outcome == "disconnect":
                # Client went away.  No point asking for resume; let outer
                # service loop accept the next connection.
                raise ConnectionResetError("client disconnected mid-engaged")

            channel.send("")
            if outcome == "stop":
                channel.send("Brake disengaged.")
            elif outcome == "fault":
                channel.send(f"Brake stopped — {info}.")
            else:
                channel.send(f"Brake stopped — communication error: {info}.")
            channel.send("")

            resume = await _prompt_yes_no(
                channel,
                f"Resume with previous values (v={last_v}, T={last_T}, Kd={last_kd:.4f})? (y/n): "
            )
            if resume:
                kd = last_kd
                continue
            else:
                channel.send("")
                break  # back to outer -> ASK_V


# ---------- TCP server runner -------------------------------------------------
async def run_tcp(host: str, port: int):
    """Listen on host:port forever, handle one client at a time."""
    brake = Brake()
    print(f"[boot] connecting to moteus on JC1...", flush=True)
    await brake.initialize()
    print(f"[boot] moteus OK", flush=True)

    active_peer = [None]   # mutable holder so the inner closure can write it

    async def handle_client(reader, writer):
        peer = writer.get_extra_info("peername")
        if active_peer[0] is not None:
            print(f"[reject] {peer} -- already serving {active_peer[0]}", flush=True)
            try:
                writer.write(
                    f"\r\nBrake controller is already in use by {active_peer[0]}.\r\n"
                    f"Disconnect that session first.\r\n".encode("utf-8")
                )
                await writer.drain()
            except Exception:
                pass
            try:
                writer.close()
                await writer.wait_closed()
            except Exception:
                pass
            return

        active_peer[0] = peer
        print(f"[connect] {peer}", flush=True)
        channel = TCPChannel(reader, writer)
        try:
            await session(channel, brake)
        except (ConnectionResetError, BrokenPipeError, asyncio.IncompleteReadError):
            print(f"[disconnect] {peer}", flush=True)
        except Exception as e:
            print(f"[error during session for {peer}] {e!r}", flush=True)
        finally:
            await brake.stop()
            try:
                writer.close()
                await writer.wait_closed()
            except Exception:
                pass
            active_peer[0] = None
            print(f"[idle] waiting for next client", flush=True)

    server = await asyncio.start_server(handle_client, host=host, port=port)
    addrs = ", ".join(str(s.getsockname()) for s in server.sockets)
    print(f"[boot] listening on {addrs}", flush=True)
    async with server:
        await server.serve_forever()


# ---------- Outer daemon loop -------------------------------------------------
async def daemon(host: str, port: int):
    while True:
        try:
            await run_tcp(host, port)
        except KeyboardInterrupt:
            raise
        except Exception as e:
            print(f"[fatal] {e!r} -- restarting in {RETRY_DELAY_S}s", flush=True)
            await asyncio.sleep(RETRY_DELAY_S)


# ---------- Sim mode (bench test) --------------------------------------------
async def run_sim():
    channel = StdinChannel()
    brake = Brake()
    print("[boot] connecting to moteus on JC1...", flush=True)
    await brake.initialize()
    print("[boot] moteus OK", flush=True)
    try:
        await session(channel, brake)
    finally:
        await brake.stop()


# ---------- Entry point ------------------------------------------------------
def main():
    p = argparse.ArgumentParser(description="Wire EDM brake controller (Pi 3B+ + pi3hat).")
    p.add_argument("--sim", action="store_true",
                   help="Skip TCP; converse on stdin/stdout (bench test).")
    p.add_argument("--host", default=DEFAULT_HOST,
                   help=f"TCP bind address (default {DEFAULT_HOST}, all interfaces)")
    p.add_argument("--port", type=int, default=DEFAULT_PORT,
                   help=f"TCP port (default {DEFAULT_PORT})")
    args = p.parse_args()

    try:
        if args.sim:
            asyncio.run(run_sim())
        else:
            asyncio.run(daemon(args.host, args.port))
    except KeyboardInterrupt:
        print("\n[exit]")
        sys.exit(130)


if __name__ == "__main__":
    main()

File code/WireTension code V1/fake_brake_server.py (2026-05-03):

#!/usr/bin/env python3
"""
fake_brake_server.py — Stand-in for the real wire_brake.py daemon.

Speaks the exact same conversational protocol over TCP as the real
Pi 3B+ brake controller, but without importing moteus or moteus_pi3hat
and without actually commanding any motor.  Use it to test
brake_console.py and exercise the full operator UX from a machine that
doesn't have the brake hardware.

Run on any machine (Pi 5, your laptop, etc.):

    python3 fake_brake_server.py                # listens on 0.0.0.0:5005
    python3 fake_brake_server.py 127.0.0.1 5005 # custom bind

Then in another terminal on the same machine:

    python3 brake_console.py 127.0.0.1 5005

You'll see the greeting, the velocity prompt, the tension prompt, the
"brake engaged" line with the computed Kd, then the resume prompt after
'stop'.  No hardware required.
"""

import argparse
import asyncio
import sys


# ---------- Calibrated input ranges (must match wire_brake.py) ----------------
V_MIN, V_MAX = 5.0, 15.0
T_MIN, T_MAX = 0.2, 3.0


def calculate_kd(v: float, T: float) -> float:
    if not (V_MIN <= v <= V_MAX):
        raise ValueError(f"velocity {v} m/min is outside [{V_MIN}..{V_MAX}].")
    if not (T_MIN <= T <= T_MAX):
        raise ValueError(f"tension {T} kgf is outside [{T_MIN}..{T_MAX}].")
    kd = (
        0.560
        - 0.218 * v
        + 2.246 * T
        - 0.107 * v * T
        + 0.0126 * v ** 2
        - 0.122 * T ** 2
    )
    if kd <= 0:
        raise ValueError(f"Kd={kd:.3f} non-positive (unstable).")
    return kd


VELOCITY_PROMPT = (
    "What velocity do you want the wire to be pulled at (m/min)?\r\n"
    f"Pick a value between {V_MIN}-{V_MAX}: "
)
TENSION_PROMPT = (
    "What tension do you want the wire to be held at (kgf)?\r\n"
    f"Pick a value between {T_MIN}-{T_MAX}: "
)


# ---------- Channel wrapper around an asyncio TCP connection -----------------
class TCPChannel:
    def __init__(self, reader, writer):
        self.reader = reader
        self.writer = writer

    def send(self, msg: str):
        try:
            self.writer.write((msg + "\r\n").encode("utf-8", errors="replace"))
        except Exception:
            pass

    async def get_line(self) -> str:
        try:
            data = await self.reader.readuntil(b"\n")
        except asyncio.IncompleteReadError:
            raise ConnectionResetError("client disconnected")
        return data.decode("utf-8", errors="replace").rstrip("\r\n")


# ---------- Fake brake (no hardware) -----------------------------------------
class FakeBrake:
    """Pretends to engage and stop a motor.  Logs what it would do."""

    async def initialize(self):
        print("[fake-brake] initialized (no hardware)", flush=True)

    async def engage(self, kd: float):
        print(f"[fake-brake] engage  kd={kd:.4f}", flush=True)

    async def stop(self):
        print("[fake-brake] stop", flush=True)


# ---------- Conversation helpers (same wording as wire_brake.py) -------------
def _greet(channel):
    channel.send("")
    channel.send("==============================================")
    channel.send("  Wire EDM Brake Controller   [FAKE BRAKE]")
    channel.send("==============================================")
    channel.send("")


async def _prompt_for_value(channel, prompt, vmin, vmax):
    while True:
        channel.send(prompt)
        line = (await channel.get_line()).strip()
        if line in ("", "?"):
            continue
        try:
            x = float(line)
        except ValueError:
            channel.send(f"  '{line}' is not a number.  Please try again.")
            continue
        if not (vmin <= x <= vmax):
            channel.send(f"  {x} is out of range.  Must be {vmin} to {vmax}.")
            continue
        return x


async def _prompt_yes_no(channel, prompt):
    while True:
        channel.send(prompt)
        line = (await channel.get_line()).strip().lower()
        if line in ("y", "yes"):
            return True
        if line in ("n", "no"):
            return False
        channel.send("  Please type 'y' or 'n'.")


async def _hold_until_stop(channel):
    """Just wait for 'stop' from the operator (no fault polling needed
    in the fake version — there's no motor)."""
    while True:
        try:
            line = (await channel.get_line()).strip().lower()
        except ConnectionResetError:
            return "disconnect"
        if line == "stop":
            return "stop"
        if line in ("?", ""):
            channel.send("  Brake is engaged.  Type 'stop' to disengage.")
        else:
            channel.send(f"  '{line}' ignored — type 'stop' to disengage.")


# ---------- Main conversation -----------------------------------------------
async def session(channel, brake):
    _greet(channel)
    last_v = last_T = last_kd = None

    while True:  # outer loop: starts over after 'no' at resume prompt
        v = await _prompt_for_value(channel, VELOCITY_PROMPT, V_MIN, V_MAX)
        T = await _prompt_for_value(channel, TENSION_PROMPT, T_MIN, T_MAX)
        try:
            kd = calculate_kd(v, T)
        except ValueError as e:
            channel.send(f"  Cannot compute Kd: {e}")
            continue
        last_v, last_T, last_kd = v, T, kd

        while True:  # ENGAGED + ASK_RESUME loop
            await brake.engage(kd)
            channel.send("")
            channel.send(f"Brake engaged.  Kd = {kd:.4f}  (v={v} m/min, T={T} kgf)")
            channel.send("Type 'stop' to disengage when finished.")
            channel.send("")

            outcome = await _hold_until_stop(channel)
            await brake.stop()

            if outcome == "disconnect":
                raise ConnectionResetError("client disconnected")

            channel.send("")
            channel.send("Brake disengaged.")
            channel.send("")

            resume = await _prompt_yes_no(
                channel,
                f"Resume with previous values (v={last_v}, T={last_T}, Kd={last_kd:.4f})? (y/n): "
            )
            if resume:
                kd = last_kd
                continue
            channel.send("")
            break  # back to outer -> ASK_V
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

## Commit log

2026-05-03 Add WireTension/: Pi5 + Pi3B+ brake controller (TCP + moteus)
2026-05-05 update readme to represent wire tension folder
2026-05-18 add raspberry pi brake controller interface and logger
2026-06-01 Add wire tension calibration workflow and documentation
2026-06-01 Revert "Add wire tension calibration workflow and documentation"
    This reverts commit 19ceb78ca3275d37a4a50eb15999cc24106a6447.
2026-06-01 Prepare wire-feed repository layout
    [18 Tooth T5 Pulley 8mm bore.3mf, Assem1.SLDASM, Assembly V4.SLDASM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]
2026-06-01 Update calibration repository link
